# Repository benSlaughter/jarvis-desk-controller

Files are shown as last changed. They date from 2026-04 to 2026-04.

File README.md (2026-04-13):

# Jarvis Desk Controller

Control a Jarvis/Jiecang standing desk via the **RJ-12 port** using the reverse-engineered serial protocol from [phord/Jarvis](https://github.com/phord/Jarvis).

Two platforms are supported:

| Platform | Interface | Features |
|---|---|---|
| **Arduino Uno** | USB Serial CLI | Direct serial commands, interactive terminal |
| **ESP32-C6** | WiFi + MQTT | Home Assistant auto-discovery, OTA updates |

## Hardware Required

### Arduino Uno
- Arduino Uno
- RJ-12 breakout / socket
- 2× 1kΩ resistors (signal protection)
- Hookup wire

### ESP32-C6
- DFRobot Beetle ESP32-C6 (or any ESP32-C6 board)
- RJ-12 breakout / socket
- 1× 1kΩ + 1× 2kΩ resistor (voltage divider for RX line)
- Hookup wire

## Wiring

The RJ-12 port is the 6-pin telephone-style jack on the desk controller (used for the optional Bluetooth add-on). Only the center 4 pins are needed.

```
 RJ-12 Jack (front view, tab down)
 ┌──────────┐
 │ 1 2 3 4 5 6 │
 └──┬─┬─┬─┬─┬─┬──┘
    │ │ │ │ │ │
    NC│ │ │ │ NC
      │ │ │ │
      │ │ │ └── Pin 5: HTX (to desk) ──[1kΩ]── Arduino Pin 3
      │ │ └──── Pin 4: VCC (5V out)    (see power notes below)
      │ └────── Pin 3: DTX (from desk) ──[1kΩ]── Arduino Pin 2
      └──────── Pin 2: GND ──────────── Arduino GND
```

### Connections Summary

| RJ-12 Pin | Label | Arduino Uno | Notes |
|---|---|---|---|
| 1 | NC | — | Not connected |
| 2 | GND | GND | Common ground (REQUIRED) |
| 3 | DTX | Pin 2 (RX) | Via 1kΩ series resistor |
| 4 | VCC | — | 5V from desk (see below) |
| 5 | HTX | Pin 3 (TX) | Via 1kΩ series resistor |
| 6 | NC | — | Not connected |

### Why series resistors?

The 1kΩ resistors protect both the Arduino and the desk controller from shorts, voltage spikes during hot-plugging, and current surges. They don't affect signal integrity at 9600 baud.

### Power Options

**For development (recommended):** Power the Arduino via USB. Leave RJ-12 Pin 4 (VCC) disconnected.

**For standalone deployment:** You *can* power the Arduino from the desk's 5V supply on RJ-12 Pin 4 → Arduino 5V pin. However:

> ⚠️ **Never connect both USB and desk 5V simultaneously** — this back-powers the USB host and can damage your computer or the desk controller. Use a diode or power switch if you need both.

### ESP32-C6 Wiring (Desk-Powered)

The ESP32 can be powered directly from the desk's 5V supply — no USB needed
after the first firmware upload (use OTA for updates).

```
                    DFRobot Beetle ESP32-C6
                    ┌─────────────────────┐
                    │                     │
RJ-12              │  VIN ←── 5V power   │
┌──────┐           │  GND ←── Ground     │
│1    6│           │                     │
│ NC  NC│           │  GPIO17 (RX) ←─┐   │
│      │           │                 │   │
│2 GND─┼──────────→│  GND            │   │
│      │           │                 │   │
│3 DTX─┼──[1kΩ]──┬─┼─────────────────┘   │
│      │         │ │                     │
│      │       [2kΩ]                     │
│      │         │ │                     │
│      │        GND│                     │
│      │           │                     │
│4 VCC─┼──────────→│  VIN (5V)           │
│      │           │                     │
│5 HTX─┼──────────→│  GPIO18 (TX)        │
│      │           │                     │
│6  NC │           └─────────────────────┘
└──────┘
```

| RJ-12 Pin | Label | ESP32-C6 | Notes |
|---|---|---|---|
| 2 | GND | GND | Common ground (REQUIRED) |
| 3 | DTX | GPIO17 (RX) | Via 1kΩ + 2kΩ voltage divider |
| 4 | VCC | VIN (5V) | Powers the ESP32 from desk |
| 5 | HTX | GPIO18 (TX) | Direct connection — 3.3V is fine |

**Parts needed:** 1× 1kΩ resistor, 1× 2kΩ resistor (or 2× 1kΩ in series)

#### Why the Voltage Divider?

The desk sends data at **5V**. The ESP32-C6 GPIOs are rated for **3.3V max**.
Without a divider, 5V goes straight into a 3.3V pin — this will damage the chip.

Two resistors drop the voltage: `5V × 2kΩ / (1kΩ + 2kΩ) = 3.33V` ✅

The TX line (ESP32→desk) doesn't need this because the ESP32 outputs 3.3V,
which the desk's 5V logic reads as HIGH (above the ~2.5V threshold).

> ⚠️ **Never connect USB and desk 5V at the same time** — this back-powers
> the USB host. Disconnect the RJ-12 before plugging in USB, or use OTA
> for all updates after the first upload.
>
> **Current budget:** The desk provides ~300mA at 5V. The ESP32-C6 draws
> ~120-180mA during WiFi activity — well within budget.

## Serial Signal Notes

Live testing on a Jiecang JCB36N2CA (Fully Jarvis) confirmed **normal UART polarity** — standard 9600/8N1 with no inversion needed. Earlier documentation suggested inverted logic, but this was not the case on the tested controller.

The code uses `SoftwareSerial` with `inverse_logic = false` (standard polarity). If you get garbage data, try toggling this flag — some controller models may differ.

## Building & Uploading (PlatformIO)

This project uses [PlatformIO](https://platformio.org/) for build/upload/serial monitoring.

### Setup

1. Install the **PlatformIO IDE** extension in VSCode (`platformio.platformio-ide`)
2. Open this folder in VSCode — PlatformIO detects `platformio.ini` automatically

### Build, Upload & Monitor

Use the PlatformIO toolbar at the bottom of VSCode, or:

```bash
# Arduino Uno
pio run -e uno
pio run -e uno --target upload

# ESP32-C6
pio run -e esp32c6
pio run -e esp32c6 --target upload

# Tests
pio test -e native

# Open serial monitor (115200 baud)
pio device monitor

# Build + upload + monitor in one shot
pio run -e uno --target upload && pio device monitor
```

### ESP32-C6 Setup

1. Copy `include/config.example.h` to `include/config.h`
2. Edit `config.h` with your WiFi SSID/password and MQTT broker IP
3. Build: `pio run -e esp32c6`
4. Upload: `pio run -e esp32c6 --target upload`
5. Monitor: `pio device monitor`

### Home Assistant Integration

The ESP32 firmware publishes MQTT auto-discovery messages. After connecting:

- A **"Jarvis Desk"** device appears automatically in Home Assistant
- **Entities:** height sensor (cm), target height (number), presets 1–4 (buttons), up/down/stop (buttons)
- **Requires** an MQTT broker (e.g., Mosquitto) configured in Home Assistant

### MQTT Topics

| Topic | Direction | Description |
|---|---|---|
| `jarvis-desk/status` | ESP→broker | Online/offline status (retained LWT) |
| `jarvis-desk/height/state` | ESP→broker | Current height in mm (retained) |
| `jarvis-desk/height/set` | broker→ESP | Move to target height in mm |
| `jarvis-desk/preset/set` | broker→ESP | Move to preset (payload: `1`–`4`) |
| `jarvis-desk/command` | broker→ESP | Send command: `up`, `down`, `stop` |
| `jarvis-desk/collision/set` | broker→ESP | Set collision sensitivity: `high`, `medium`, `low` |

### OTA Updates

After the first upload via USB, subsequent updates can use OTA:

```bash
pio run -e esp32c6 --target upload --upload-port jarvis-desk.local
```

### Alternative: Arduino IDE

If you prefer the Arduino IDE, copy files from `src/` and `include/` into a single
folder named `jarvis-desk-controller/`, rename `main.cpp` → `jarvis-desk-controller.ino`,
and open it in the Arduino IDE.

## Usage

Open the Serial Monitor at **115200 baud**. Type commands and press Enter:

| Command | Action |
|---|---|
| `up` / `raise`| Raise desk one step |
| `down`/`lower`| Lower desk one step |
| `1` `2` `3` `4`| Move to memory preset |
| `save1`..`save4`| Save current height to preset|
| `height` | Request current height |
| `settings` | Request all desk settings |
| `limits` | Request min/max limits |
| `wake` | Send wake signal |
| `cm` / `in` | Set display units |
| `status` | Show connection state |
| `help` | List all commands |

### What you'll see

```
=== Jarvis Desk Controller ===
Type 'help' for commands

Waking desk...
[DESK] HEIGHT (05 06 07)  height=1286
> Moving to preset 1
[DESK] HEIGHT (03 CA 07)  height=970
```

## Protocol Reference

- **UART:** 9600 baud, 8N1, normal polarity (not inverted)
- **Packets:** `[addr][addr][cmd][len][params...][checksum][0x7E]`
- **Handset address:** `0xF1 0xF1`
- **Controller address:** `0xF2 0xF2`
- **Checksum:** Low byte of `(cmd + len + params...)`, i.e. `& 0xFF`

Full protocol documentation: https://github.com/phord/Jarvis

## Protocol Discoveries (Live Testing)

Tested on a **Jiecang JCB36N2CA** (Fully Jarvis, RJ-12 port). The RJ-12 interface works standalone — no handset required.

### Confirmed Commands (Handset → Desk)

| Cmd  | Name | Params | Response | Notes |
|---|---|---|---|---|
| 0x01 | RAISE | 0 | HEIGHT stream | Continuous raise when sent repeatedly |
| 0x02 | LOWER | 0 | HEIGHT stream | Continuous lower when sent repeatedly |
| 0x05 | MOVE_1 | 0 | HEIGHT stream | Moves to preset 1, auto-stops |
| 0x06 | MOVE_2 | 0 | HEIGHT stream | Moves to preset 2, auto-stops |
| 0x07 | SETTINGS | 0 | POS_1–4 + HEIGHT | Returns all 4 presets and current height |
| 0x0C | PHYS_LIMITS| 0 | 0x07 (HI HI LO LO) | Physical motion limits: max/min in mm |
| 0x1B | GOTO_HEIGHT| 2 (HI, LO)| 0x1B echo + HEIGHT stream | **Native goto-height.** Desk handles accel/decel/stop |
| 0x20 | LIMITS | 0 | 0x20 (00) | User-set limits bitmask. 0x00 = none set |
| 0x27 | MOVE_3 | 0 | HEIGHT stream | Moves to preset 3, auto-stops |
| 0x28 | MOVE_4 | 0 | HEIGHT stream | Moves to preset 4, auto-stops |
| 0x29 | WAKE | 0 | none (display only) | Wakes display. No data response on RJ-12 |
| 0x2B | STOP | 0 | none | Stops all movement immediately |

### Controller Responses

| Resp | Name | Params | Meaning |
|---|---|---|---|
| 0x01 | HEIGHT | 3 | {P0,P1} = height mm, P2 = flags (always 0x0F here) |
| 0x07 | PHYS_LIMITS| 4 | {P0,P1} = max mm, {P2,P3} = min mm |
| 0x1B | GOTO_ACK | 2 | Echoes target height |
| 0x20 | LIMITS | 1 | Bitmask of user-set limits |
| 0x25–0x28 | POS_1–4 | 2 | Raw encoder value (NOT display mm) |

### Key Observations

- **Normal UART polarity** — standard 9600/8N1, no inversion needed.
- **GOTO_HEIGHT (0x1B)** is the cleanest move method — desk handles acceleration, deceleration, and auto-stop.
- **STOP (0x2B)** halts movement immediately. ESPHome uses wake + stop as an init sequence.
- **Preset values** are raw encoder positions, not display millimeters.
- **Height offset:** Display height has a ~2.4 cm offset from physical (tape-measure) height.
- **Physical limits** on tested unit: 76.5–125.3 cm reported, ~74.1–122.9 cm actual.
- **No-response commands:** 0x0E (UNITS), 0x19 (MEM_MODE), 0x1D (COLL_SENS) — these are setters that likely need parameters, or are RJ-45 only.

## RJ-12 vs RJ-45

This project uses the **RJ-12** interface (6-pin, Bluetooth add-on port). The larger **RJ-45** port (8-pin, handset port) has additional button mux lines (HS0-HS3) not available on RJ-12.

On RJ-12, some responses differ:
- `SETTINGS` returns fewer response packets
- `LIMIT_STOP` and `REP_PRESET` are not sent

## Troubleshooting

| Problem | Try |
|---|-----|
| No response from desk | Check GND connection. Try `wake` command repeatedly. |
| Garbage data | Toggle `inverse_logic` in the SoftwareSerial constructor. Normal polarity (false) confirmed on JCB36N2CA. |
| Partial/corrupt packets | Check series resistors are connected. Reduce Serial.print debug output. |
| Desk doesn't move | The raise/lower commands send a single step. You may need to send repeatedly. |

## License

This project is for personal/educational use. The protocol was reverse-engineered by [phord](https://github.com/phord/Jarvis).

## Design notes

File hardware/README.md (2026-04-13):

# Jarvis Desk Controller — Hardware

Custom PCB to connect a DFRobot Beetle ESP32-C6 to a Jarvis standing desk via
the RJ-12 control port. The board provides a voltage divider on the desk→MCU
data line (5 V → 3.3 V logic) and breaks out power + UART signals.

## Bill of Materials

| Ref | Part | Value | Package / Footprint | Qty | Example Part Number |
|-----|---|---|---|-----|---|
| U1 | DFRobot Beetle ESP32-C6 | — | 2×7 pin header, 2.54 mm pitch | 1 | DFRobot DFR1117 |
| J1 | RJ-12 socket | 6P6C | Through-hole, right-angle | 1 | Amphenol 54601-906LF |
| R1 | Resistor | 1 kΩ | 0805 (or 1/4 W through-hole) | 1 | — |
| R2 | Resistor | 2 kΩ | 0805 (or 1/4 W through-hole) | 1 | — |
| — | Pin headers (female) | 2.54 mm | 1×7, through-hole | 2 | — |

> **Note:** If you use through-hole resistors, increase the board width by a
> few mm to accommodate them.

## Assembly Instructions

### 1. Order the PCB

See [PCB Ordering Guide](#pcb-ordering-guide) below or the detailed
[KiCad Guide](kicad-guide.md) for Gerber generation.

### 2. Solder Components (order matters)

1. **SMD resistors first** (if using 0805) — R1 (1 kΩ) and R2 (2 kΩ). They
   sit on the top side between the RJ-12 footprint and the pin headers.
2. **RJ-12 socket (J1)** — Push through from the top, solder on the bottom.
   The socket opening should face the board edge.
3. **Female pin headers** — Two 1×7 strips for the Beetle. Solder from the
   bottom so the Beetle plugs in on top.
4. **Plug in the Beetle** — The USB-C port should face away from the RJ-12
   socket.

### 3. Connect to Desk

Use a straight-through RJ-12 6P6C cable (all 6 pins wired 1-to-1). Plug one
end into the controller's handset port and the other into J1.

### 4. Flash Firmware

Connect USB-C to the Beetle and flash with PlatformIO:

```bash
pio run -t upload
```

## PCB Ordering Guide

### JLCPCB

1. In KiCad, go to **File → Fabrication Outputs → Gerbers (.gbr)**.
2. Also generate the drill file (Excellon format).
3. Zip all Gerber + drill files together.
4. Go to <https://www.jlcpcb.com/> → **Order Now** → upload the zip.
5. Recommended settings:
   - **Layers:** 2
   - **PCB Thickness:** 1.6 mm
   - **Surface Finish:** HASL (lead-free)
   - **PCB Color:** any (green is cheapest)
   - **Dimensions:** ~35 mm × 25 mm
   - **Qty:** 5 (minimum)
6. Total cost is typically **$2–5 USD** + shipping for 5 boards.

### PCBWay

Same Gerber zip works. Upload at <https://www.pcbway.com/> → **Instant Quote**.
Use the same settings as above.

## Schematic Overview

See [schematic.md](schematic.md) for the full ASCII schematic and component
details.

```
RJ12 Pin 2 (GND) ───────────────── Beetle GND
RJ12 Pin 3 (DTX) ──[R1 1kΩ]──┬── Beetle GPIO17 (RX)
                               │
                            [R2 2kΩ]
                               │
                              GND
RJ12 Pin 4 (VCC) ───────────────── Beetle VIN (5V)
RJ12 Pin 5 (HTX) ───────────────── Beetle GPIO18 (TX)
```

## Files

| File | Description |
|---|---|
| [README.md](README.md) | This file — BOM, assembly, ordering |
| [schematic.md](schematic.md) | ASCII schematic and component details |
| [kicad-guide.md](kicad-guide.md) | Step-by-step KiCad PCB design guide |

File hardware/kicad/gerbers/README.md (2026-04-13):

# Gerber Export Instructions

`kicad-cli` is not installed on this system. To generate Gerber files:

## Option 1: KiCad GUI
1. Open `jarvis-desk.kicad_pcb` in KiCad 8
2. File → Plot (or Fabrication → Plot)
3. Select layers: F.Cu, B.Cu, F.SilkS, B.SilkS, F.Mask, B.Mask, Edge.Cuts
4. Output directory: `gerbers/`
5. Click "Plot"
6. Click "Generate Drill Files" for drill data

## Option 2: kicad-cli (if installed)
```bash
kicad-cli pcb export gerbers --output hardware/kicad/gerbers/ hardware/kicad/jarvis-desk.kicad_pcb
kicad-cli pcb export drill --output hardware/kicad/gerbers/ hardware/kicad/jarvis-desk.kicad_pcb
```

## Fabrication
Upload the generated Gerber + drill files as a zip to your PCB manufacturer (JLCPCB, PCBWay, OSH Park, etc.).

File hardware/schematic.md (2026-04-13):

# Jarvis Desk Controller — Schematic

## Circuit Description

The Jarvis desk communicates over a 5 V UART bus exposed on an RJ-12 (6P6C)
connector. The Beetle ESP32-C6 runs on 3.3 V logic, so the desk→MCU receive
line needs a voltage divider (R1 + R2) to step 5 V down to ~3.3 V. The MCU→desk
transmit line can drive directly since 3.3 V is above the 5 V CMOS high
threshold on most desk controllers.

## ASCII Schematic

```
                        Beetle ESP32-C6
                     ┌───────────────────┐
                     │                   │
 RJ-12 6P6C         │  VIN (5V)  GND    │
┌──────────┐         │   ●        ●      │
│          │         │   │        │      │
│  Pin 1   │  NC     │   │        │      │
│          │         │   │        │      │
│  Pin 2   │──GND────┼───┼────────┘      │
│  (GND)   │         │   │               │
│          │         │   │               │
│  Pin 3   │──DTX──┐ │   │    GPIO17 ●   │
│  (DTX)   │       │ │   │    (RX)   │   │
│          │      ┌┴┐│   │          │   │
│          │      │R││   │          │   │
│          │      │1││   │          │   │
│          │      │ ││   │          │   │
│          │      │1││   │          │   │
│          │      │k││   │          │   │
│          │      └┬┘│   │          │   │
│          │       ├──┼───┼──────────┘   │
│          │       │  │   │               │
│          │      ┌┴┐ │   │               │
│          │      │R│ │   │               │
│          │      │2│ │   │               │
│          │      │ │ │   │               │
│          │      │2│ │   │               │
│          │      │k│ │   │               │
│          │      └┬┘ │   │               │
│          │       │  │   │               │
│          │      GND │   │               │
│          │         │   │               │
│  Pin 4   │──VCC────┼───┘               │
│  (VCC)   │         │                   │
│          │         │        GPIO18 ●   │
│  Pin 5   │──HTX────┼───────(TX)────┘   │
│  (HTX)   │         │                   │
│          │         │                   │
│  Pin 6   │  NC     │                   │
│          │         │                   │
└──────────┘         └───────────────────┘
```

## Simplified Netlist

```
RJ12.2  (GND) ───────────────────────── Beetle.GND
RJ12.3  (DTX) ───── R1 (1kΩ) ────┬──── Beetle.GPIO17 (RX)
                                  │
                              R2 (2kΩ)
                                  │
                                 GND
RJ12.4  (VCC) ───────────────────────── Beetle.VIN (5V)
RJ12.5  (HTX) ───────────────────────── Beetle.GPIO18 (TX)
```

## Voltage Divider Calculation

```
V_out = V_in × R2 / (R1 + R2)
V_out = 5.0 V × 2000 / (1000 + 2000)
V_out = 5.0 V × 0.667
V_out ≈ 3.33 V
```

This is within the ESP32-C6 GPIO input range (max 3.6 V).

## Component Details

### U1 — DFRobot Beetle ESP32-C6 (DFR1117)

- **Pinout (left side, top to bottom):** VIN, GND, 3V3, GPIO0, GPIO1, GPIO15, GPIO23
- **Pinout (right side, top to bottom):** GPIO22, GPIO21, GPIO20, GPIO19, GPIO18, GPIO17, GPIO4
- **Used pins:**
  - VIN — 5 V power input from desk
  - GND — common ground
  - GPIO17 — UART RX (desk DTX → MCU, via voltage divider)
  - GPIO18 — UART TX (MCU → desk HTX, direct)
- **Form factor:** 25 mm × 20.5 mm, 2×7 pin header at 2.54 mm pitch

### J1 — RJ-12 6P6C Socket

- **Type:** Through-hole, right-angle, PCB mount
- **Suggested parts:**
  - Amphenol 54601-906LF
  - Molex 95501-2661
  - SparkFun PRT-00132
- **Pin numbering** (looking into the socket opening, latch on top):
  - Pin 1: NC (not connected)
  - Pin 2: GND
  - Pin 3: DTX (desk transmit → MCU receive)
  - Pin 4: VCC (5 V)
  - Pin 5: HTX (MCU transmit → desk receive)
  - Pin 6: NC (not connected)

### R1 — 1 kΩ Resistor

- **Package:** 0805 SMD (preferred) or 1/4 W axial through-hole
- **Tolerance:** 1% or 5% — either is fine
- **Purpose:** Upper leg of voltage divider

### R2 — 2 kΩ Resistor

- **Package:** 0805 SMD (preferred) or 1/4 W axial through-hole
- **Tolerance:** 1% or 5% — either is fine
- **Purpose:** Lower leg of voltage divider (to GND)

## Net Summary

| Net Name | Connected Pins |
|---|---|
| GND | RJ12.2, Beetle.GND, R2 (low side) |
| VCC_5V | RJ12.4, Beetle.VIN |
| DTX_5V | RJ12.3, R1 (high side) |
| DTX_3V3 | R1 (low side), R2 (high side), Beetle.GPIO17 |
| HTX | RJ12.5, Beetle.GPIO18 |

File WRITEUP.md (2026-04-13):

# Hacking My Jarvis Desk with an Arduino

I wanted to control my Fully Jarvis standing desk from a computer. No WiFi modules,
no cloud services, no Bluetooth — just an Arduino Uno, an RJ-12 cable, and some
reverse-engineering.

This is what I found.

## The Setup

- **Desk:** Fully Jarvis with Jiecang controller
- **Controller port:** RJ-12 (6-pin, the Bluetooth add-on port)
- **Microcontroller:** Arduino Uno
- **Total cost:** ~£20 (Arduino + RJ-12 socket)
- **Wires needed:** 3 (GND, TX, RX)

### Wiring

```
RJ-12 Pin 2 (GND) → Arduino GND
RJ-12 Pin 3 (DTX) → Arduino Pin 2
RJ-12 Pin 5 (HTX) → Arduino Pin 3
Pin 4 (5V)        → Leave disconnected (USB power is fine)
```

No resistors. No level shifting. Both sides are 5V. Done.

## What Went Wrong First

Pretty much everything.

**Wiring mistake #1:** I had pins 4 and 5 swapped — feeding the desk's 5V power
supply into a data pin. Oops.

**Polarity mistake:** The original [phord/Jarvis](https://github.com/phord/Jarvis)
docs describe "5V pullups, mark=low" which sounds like inverted serial. It's not.
The RJ-12 port uses **standard UART polarity**. I figured this out by enabling
debug mode and moving the desk manually — the raw bytes were bit-inverted `F2 F2`
packets, which only makes sense if the serial was reading them wrong.

**The fix:** Normal `SoftwareSerial`, no inverse logic. 9600 baud, 8N1. Standard stuff.

## What Works

Once the wiring and polarity were sorted, everything just... worked.

### Reading
- Current height (in mm or tenths-of-inches depending on display units)
- All 4 memory preset positions
- Physical limits of the desk (min/max travel)
- User-set height limits

### Moving
- Raise/lower (continuous, like holding the button)
- Move to any of the 4 presets
- **Go to a specific height** — `goto 800` moves to 80.0cm and the desk handles
  acceleration, deceleration, and stopping. This was the big discovery.
- Stop movement

### The `goto` Command

This is the good stuff. Command `0x1B` with a 2-byte target height — the desk
does everything. No PID loops, no polling, no "am I there yet". Send it and forget it.

```
goto 800
> Native goto 800mm (80.0cm) from 744mm
[DESK] GOTO_HEIGHT (03 20)  target=80.0cm
[DESK] HEIGHT (02 E9 0F)  74.5cm
[DESK] HEIGHT (03 07 0F)  77.5cm
[DESK] HEIGHT (03 1C 0F)  79.6cm
> Target height reached: 800mm
[DESK] HEIGHT (03 1F 0F)  79.9cm
```

Not documented in phord's README. Found it in the
[ESPHome Jiecang component](https://github.com/Rocka84/esphome_components) source code,
confirmed it works on our hardware.

### The `scan` Command

I added a `scan` command that queries every known read command and dumps the results.
Change a setting on the handset, run scan, diff the output. This is how we mapped
most of the protocol.

## The Protocol

Packets look like this:
```
[addr] [addr] [cmd] [len] [params...] [checksum] [0x7E]
```

- Handset address: `0xF1 0xF1`
- Controller address: `0xF2 0xF2`
- Checksum: `(cmd + len + params) & 0xFF`
- EOM: always `0x7E`

### Commands That Work Over RJ-12

| Cmd | What it does | Response |
|-----|---|---|
| 0x01 | Raise (one step) | HEIGHT stream |
| 0x02 | Lower (one step) | HEIGHT stream |
| 0x05/06 | Move to preset 1/2 | HEIGHT stream, auto-stops |
| 0x07 | Get all settings | POS_1-4 + HEIGHT |
| 0x08 | ??? | 0x05 with FF FF (or 00 06 sometimes) |
| 0x09 | ??? | 0x06 with 01 |
| 0x0C | Physical limits | 0x07 with max/min in mm |
| 0x1B | **Go to height** | Echo + HEIGHT stream, auto-stops |
| 0x1C | ??? | 0x1C with 0x35 (firmware version?) |
| 0x20 | Query limits | 0x20 bitmask + SET_MAX/SET_MIN if set |
| 0x23 | Clear limits | 0x20 confirmation |
| 0x27/28 | Move to preset 3/4 | HEIGHT stream, auto-stops |
| 0x29 | Wake | Wakes display, no data response |
| 0x2B | Stop | Stops movement, no data response |

### What Doesn't Work Over RJ-12

- **Set units** (0x0E) — handset only
- **Anti-collision** (0x1D) — not readable, probably RJ-45 only
- **BT app commands** (0xA0-0xAD) — no response, BT module only
- **Lock/brightness** — handset-local, no protocol traffic at all

### The HEIGHT Response

```
F2 F2 01 03 HH HL P2 checksum 7E
```

`{HH, HL}` = height in mm (CM mode) or tenths-of-inches (inch mode).
`P2` = always `0x0F` on our controller. phord saw `0x07`. Nobody knows what it is.
It doesn't change with units, calibration, movement, or any setting we tested.

## Things We Learned the Hard Way

### Don't Set Min = Max Height

We set both min and max limits to the same height (84.5cm). The desk got stuck.
Completely stuck. Couldn't move from the handset or the Arduino. Clearing the limits
via protocol didn't help — had to **unplug the desk from the wall** and wait.

Power cycle fixed it. But yeah, don't do that.

### Calibration Changes Everything (Uniformly)

When you recalibrate the height on the handset, every height value shifts by the
same offset. Physical limits, current height, all of it. But preset raw encoder
values stay the same — they're hardware positions, not display values.

No software offset needed — just calibrate via the handset and the protocol
values automatically match reality.

### Anti-Collision Sensitivity: Writable Over RJ-12

We physically tested this. Set sensitivity to HIGH via `0x1D 0x01`, raised the desk,
and pushed down with hand pressure — stopped easily at ~91cm. Set to LOW via
`0x1D 0x03`, same test — needed full body weight to trigger it, and it still got
to ~87cm before stopping.

**Setter commands work over RJ-12**, even though we can't read the values back.
The controller accepts and applies them immediately.

| Sensitivity | Command | Force to stop |
|---|---|---|
| HIGH | `0x1D 0x01` | Moderate hand pressure |
| LOW | `0x1D 0x03` | Full body weight |

### 0x1F Is the Controller-Level Lock

We found this by trying something nobody documented — sending 0x1F as a
**setter** instead of a getter:

```
raw 1F 01    → desk locked. Completely. Handset couldn't override it.
raw 1F 00    → didn't unlock
power cycle  → unlocked
```

This is different from the handset's Lock/Unlock menu option (which is local
to the handset). Command 0x1F locks the **motor controller itself**. No known
software unlock — power cycle only.

Don't do this unless you're OK with pulling the plug.

### Presets Are Raw Encoder Values

The POS_1-4 responses are internal encoder tick counts, not display millimetres.
There's a calibration formula somewhere (`height = offset + raw * 0.0642` per
phord/Jarvis#21) but the exact scaling varies by controller.

### The Desk Shows the Fully Logo When You Scan

The SETTINGS command (0x07) is what the handset sends on boot. The controller
wakes up and shows the brand logo. We're basically impersonating a handset.

### Handset-Local Settings

These don't go through the controller at all — no protocol traffic:
- Lock/unlock
- Screen brightness
- Button brightness

We confirmed this by running scan before and after toggling each one. Zero changes.

## RJ-12 vs RJ-45 Capability

| Feature | RJ-12 Read | RJ-12 Write | RJ-45 (per phord) |
|---|---|---|---|
| Height | ✅ | — | ✅ |
| Presets | ✅ raw values | ✅ move + save | ✅ |
| Physical limits | ✅ | — | ✅ |
| User limits | ✅ | ✅ set + clear | ✅ |
| Anti-collision | ❌ | ✅ confirmed | ✅ read + write |
| Units | ❌ | ❌ | ✅ |
| Memory mode | ❌ | Likely works | ✅ |
| Controller lock | ❌ | ✅ (0x1F 01) | Unknown |
| Goto height | — | ✅ (0x1B) | ✅ |
| Stop | — | ✅ (0x2B) | ✅ |

## What's Still Unknown

| Response | Our data | Best guess |
|---|---|---|
| 0x05 (from 0x08) | FF FF (once saw 00 06) | Unknown. Resets on power cycle |
| 0x06 (from 0x09) | 01 | Protocol version or controller type |
| 0x1C (from 0x1C) | 0x35 | Firmware version or model ID |
| HEIGHT P2 byte | always 0x0F | Hardware constant. Doesn't change with anything |
| 0x1F unlock | ??? | No software unlock found. Power cycle only |

## Standing on the Shoulders of Giants

None of this would have been possible without:

- [phord/Jarvis](https://github.com/phord/Jarvis) — the original reverse-engineering
  that started it all
- [Rocka84/esphome_components](https://github.com/Rocka84/esphome_components) —
  the Jiecang ESPHome component that confirmed goto-height works
- [auchter/esphome-jcb35n2](https://github.com/auchter/esphome-jcb35n2) —
  the alternative protocol for simpler controllers
- [Home Assistant community](https://community.home-assistant.io/t/desky-standing-desk-esphome-works-with-desky-uplift-jiecang-assmann-others/383790) —
  the Desky thread with years of collective knowledge
- [pimp-my-desk](https://gitlab.com/pimp-my-desk/desk-control/jiecang-reverse-engineering) —
  more Jiecang protocol details
- Everyone in [Jarvis#33](https://github.com/phord/Jarvis/issues/33) who
  decompiled the BT app and shared their findings

## What's Next

- Proper CLI commands for collision sensitivity, memory mode, units
- Sit/stand timer with reminders

## The ESP32 Port

After getting everything working on the Arduino Uno, the next step was obvious: WiFi.

The **DFRobot Beetle ESP32-C6** is tiny enough to hide behind the desk, and has
HardwareSerial so no more SoftwareSerial timing issues. The main catch is voltage
levels — the ESP32-C6 is 3.3V logic, and the desk outputs 5V. A simple 1kΩ + 2kΩ
voltage divider on the RX line solves that. The TX direction works as-is since
3.3V is above the desk's input threshold.

The whole thing runs off the desk's own 5V supply (RJ-12 Pin 4 → ESP32 VIN).
No USB cable needed after the first firmware upload — OTA handles updates over WiFi.

The firmware connects to WiFi and an MQTT broker, then publishes Home Assistant
auto-discovery messages. Within seconds of powering on, a "Jarvis Desk" device
appears in HA with a height sensor, target height number input, preset buttons,
and movement controls. No YAML configuration needed.

Height updates are debounced — published at most every 500ms during movement,
then a final update when the desk settles. MQTT reconnects with exponential backoff.

The desk protocol library (`JarvisDesk`) is shared between both platforms — only
the entry points (`main_uno.cpp` and `main_esp32.cpp`) differ. The Uno version
is a serial CLI; the ESP32 version is a headless MQTT bridge.

The code is in `src/main_esp32.cpp`. Config goes in `include/config.h`
(copy from `config.example.h`).

The code is a PlatformIO project with 47 unit tests. The research journal with
raw packet captures is in `RESEARCH.md`.

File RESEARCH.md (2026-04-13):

# Jarvis Desk Protocol — Research Journal

> Reverse-engineering notes for a **Fully Jarvis** standing desk with a **Jiecang** controller,
> communicating via the **RJ-12** (Bluetooth add-on) port using an **Arduino Uno**.
>
> Protocol reference: [phord/Jarvis](https://github.com/phord/Jarvis)
> ESPHome reference: [Rocka84/esphome_components](https://github.com/Rocka84/esphome_components/tree/master/components/jiecang_desk_controller)

---

## Hardware Setup

| Item | Details |
|---|---|
| Desk | Fully Jarvis standing desk |
| Controller | Jiecang (model TBD — RJ-12 port present) |
| Handset | Touchpanel with 4 memory presets |
| Microcontroller | Arduino Uno (ATmega328P, 5V logic) |
| Connection | RJ-12 6-pin jack (Bluetooth add-on port) |
| UART | 9600 baud, 8N1, **normal polarity** (NOT inverted) |

### Wiring (RJ-12 → Arduino Uno)

```
RJ-12 Pin 2 (GND) → Arduino GND
RJ-12 Pin 3 (DTX) → Arduino Digital Pin 2 (RX)
RJ-12 Pin 4 (VCC) → Disconnected (USB powered for dev)
RJ-12 Pin 5 (HTX) → Arduino Digital Pin 3 (TX)
```

No resistors, no level shifting — both sides are 5V logic.

---

## Journey Log

### 2026-04-11: Project Scaffolding

- Created PlatformIO project targeting Arduino Uno
- Implemented the phord/Jarvis UART protocol: packet builder, checksum, parser state machine
- Serial monitor CLI with commands: up, down, stop, presets, settings, height, etc.
- Added features: continuous raise/lower with 30s safety timeout, move-to-height,
  raw hex debug mode, auto-detect serial polarity
- 47 native unit tests for protocol and parser — all passing

### 2026-04-11: First Connection Attempt (FAILED)

**Problem:** Auto-detect found no desk on either polarity.

**Root cause 1 — Wiring error:** RJ-12 pins 4 (VCC) and 5 (HTX) were swapped.
Pin 4 is 5V power, pin 5 is the data line. We had the desk's 5V power going into
a data pin and the data line tied to constant 5V.

**Fix:** Disconnected pin 4 (VCC) entirely, moved pin 5 (HTX) to Arduino D3.

**Root cause 2 — Still no response after wiring fix.**
Enabled debug mode and moved desk manually with the RJ-45 handset controller.
Saw data:
```
RX: 83 83 F9 F9 E3 E1 B7 03 00
```

These are **bit-inverted** `F2 F2` packets! The code was trying inverted serial
first (based on the phord docs saying "5V pullups, mark=low"), but this controller
uses **normal/standard UART polarity**.

**Fix:** Changed default to normal polarity. Result:
```
[DESK] HEIGHT (03 12 0F)  height=786
```

**Lesson learned:** The phord/Jarvis docs describe an older controller model.
The Jiecang RJ-12 interface uses standard UART, confirmed by the
ESPHome jiecang_desk_controller component.

### 2026-04-12: Live Testing & Protocol Discovery

Connected via serial monitor. Systematically tested all features and probed
unknown commands.

#### Working Features
- **settings** → Returns POS_1–4 (raw encoder values) + current HEIGHT
- **height** → Works via SETTINGS command (0x07)
- **limits** → Returns 0x00 (no user-set limits)
- **raise/lower** → Continuous movement works, stop works
- **preset 1–4** → Desk moves to stored position, auto-stops
- **debug mode** → Raw hex byte output for troubleshooting

#### Major Discovery: GOTO_HEIGHT (0x1B)

The desk supports a **native goto-height command** — not documented in the
phord/Jarvis README but used by the ESPHome component:

```
Handset sends:  F1 F1 1B 02 HI LO checksum 7E
Desk responds:  F2 F2 1B 02 HI LO checksum 7E  (echo)
                F2 F2 01 03 HH HL 0F checksum 7E  (HEIGHT stream until settled)
```

Where `{HI, LO}` = target height in the same units as HEIGHT reports (mm on this desk).

**Test:** Sent `raw 1B 03 06` (target = 774 = 77.4cm). Desk moved from 80.1cm
down to 77.4cm and auto-stopped. The desk handles acceleration, deceleration,
and final positioning — no need for the crude continuous raise/lower approach!

#### STOP Command (0x2B)

Also discovered (via ESPHome reference) that **0x2B** is a proper STOP command.
The phord docs only document 0x29 (WAKE), which on our controller only wakes
the display and doesn't stop movement or trigger data responses.

---

## Protocol Probe Results

### Commands Tested (Handset → Desk, 0xF1 address)

| Cmd | Name | Params | Response | Our Data | Notes |
|-----|---|---|---|---|---|
| 0x01 | RAISE | 0 | HEIGHT stream | ✅ | Send repeatedly for continuous raise |
| 0x02 | LOWER | 0 | HEIGHT stream | ✅ | Send repeatedly for continuous lower |
| 0x05 | MOVE_1 | 0 | HEIGHT stream | ✅ | Desk moves to preset 1, auto-stops |
| 0x06 | MOVE_2 | 0 | HEIGHT stream | ✅ | Desk moves to preset 2, auto-stops |
| 0x07 | SETTINGS | 0 | POS_1-4 + HEIGHT | ✅ | Returns all 4 presets + current height |
| 0x08 | UNKNOWN_08 | 0 | 0x05 (FF FF) | ✅ | Docs saw 00 00 or FF FF. Unknown purpose |
| 0x09 | UNKNOWN_09 | 0 | 0x06 (01) | ✅ | Consistent with docs. Unknown purpose |
| 0x0C | PHYS_LIMITS | 0 | 0x07 | 04 E5 02 FD | **Confirmed:** {P0,P1}=1253 max, {P2,P3}=765 min (mm) |
| 0x0E | UNITS | 1 | — | no response | Setter — needs param. Sent without param |
| 0x19 | MEM_MODE | 1 | — | no response | Setter — needs param. Sent without param |
| 0x1B | **GOTO_HEIGHT** | 2 (HI,LO) | 0x1B echo + HEIGHT | **03 06** | 🆕 **Native goto!** Desk moves to target, auto-stops |
| 0x1C | UNKNOWN_1C | 0 | 0x1C | 35 | Docs saw 0x0A. We got 0x35 (53). Firmware version? |
| 0x1D | COLL_SENS | 1 | — | no response | Setter — needs param. Sent without param |
| 0x1F | UNKNOWN_1F | 0 | 0x1F | 00 | Matches docs. Unknown purpose |
| 0x20 | LIMITS | 0 | 0x20 | 00 | No user-set min/max limits configured |
| 0x27 | MOVE_3 | 0 | HEIGHT stream | ✅ | Desk moves to preset 3, auto-stops |
| 0x28 | MOVE_4 | 0 | HEIGHT stream | ✅ | Desk moves to preset 4, auto-stops |
| 0x29 | WAKE | 0 | none (display) | ✅ | Wakes desk display. **No data response on RJ-12** |
| 0x2B | **STOP** | 0 | none | ✅ | 🆕 Stops movement. From ESPHome reference |

### Desk Responses Observed (Controller → Handset, 0xF2 address)

| Resp | Name | Params | Meaning |
|---|---|---|---|
| 0x01 | HEIGHT | 3: HH HL 0F | Current height. {P0,P1} = mm. P2 always 0x0F on this controller |
| 0x05 | UNK_05 | 2 | Response to 0x08. Seen: FF FF |
| 0x06 | UNK_06 | 1 | Response to 0x09. Seen: 01 |
| 0x07 | PHYS_LIMITS | 4 | Response to 0x0C. {P0,P1}=max mm, {P2,P3}=min mm |
| 0x1B | GOTO_ACK | 2 | Echoes target height from 0x1B command |
| 0x1C | UNK_1C | 1 | Response to 0x1C. Seen: 0x35 |
| 0x1F | UNK_1F | 1 | Response to 0x1F. Seen: 0x00 |
| 0x20 | LIMITS | 1 | Bitmask: 0x00=none, 0x01=max, 0x10=min, 0x11=both |
| 0x25 | POS_1 | 2 | Preset 1 stored value (raw encoder, NOT display mm) |
| 0x26 | POS_2 | 2 | Preset 2 stored value |
| 0x27 | POS_3 | 2 | Preset 3 stored value |
| 0x28 | POS_4 | 2 | Preset 4 stored value |

---

## Experiment Results

### Experiment 1: HEIGHT P2 vs Units (2026-04-12)

Changed display units via the handset controller and compared HEIGHT responses.

| Mode | HEIGHT P0,P1 | HEIGHT P2 | Conversion |
|---|---|---|---|
| CM | 03 07 (775) | **0x0F** | 77.5cm |
| Inches | 01 31 (305) | **0x0F** | 30.5" = 77.5cm ✅ |

**Conclusions:**
- ✅ Height value changes with units: mm in CM mode, tenths-of-inches in inch mode
- ❌ **P2 does NOT change with units** — still 0x0F in both modes
- ✅ Physical limits (0x07 response) always return mm regardless of units
- ❌ Set-units command (0x0E) does NOT work over RJ-12
- P2 = 0x0F remains a mystery — likely controller model/capability flags

### Experiment 2: BT App Commands (2026-04-12)

Tested decompiled Bluetooth app commands over RJ-12:

| Cmd | Name | Response |
|-----|---|---|
| 0xA0 | PATCH | ❌ No response |
| 0xA2 | FETCH_STAND_TIME | ❌ No response |
| 0xA6 | FETCH_STAND_TIME (alt) | ❌ No response |
| 0xAA | FETCH_ALL_TIME | ❌ No response |
| 0xAD | SET_MEMORY_HEIGHT | ❌ No response |

**Conclusion:** BT app commands are not processed over the RJ-12 UART.
These likely require the BT module to intercept and handle them separately.

### Experiment 3: Limits Set/Clear via RJ-12 (2026-04-12)

**Setting limits works:**
- Set max height at 84.5cm via handset → `LIMITS (01)`, `SET_MAX (03 4D) = 845` ✅
- Set min height at 84.5cm via handset → `LIMITS (10)`, `SET_MIN (03 4D) = 845` ✅
- Matches phord's docs: 0x00=none, 0x01=max-only, 0x10=min-only, 0x11=both

**Clearing limits works (protocol level):**
- `raw 23 01` (clear max) → controller responds `LIMITS (00)` ✅
- `raw 23 02` (clear min) → controller responds `LIMITS (00)` ✅

**⚠️ CRITICAL WARNING — LIMITS INCIDENT:**
After setting min AND max to the same height (84.5cm) and then clearing them
via RJ-12, the desk became **stuck and unable to move**. The controller reported
`LIMITS (00)` (cleared), but the desk refused all movement commands — both from
the Arduino AND from the handset. The handset menu was still accessible but
movement was completely locked out.

**Resolution required:** Power cycling the desk (unplugging from wall power).

**Lesson learned:** Setting min=max to the same height creates a "zero range"
condition that may put the controller into a safety lockout state that persists
even after the limits are cleared via protocol commands. **Never set min and max
to the same height.** The controller may need a full power cycle to recover.

**Also confirmed:**
- Anti-collision sensitivity change: NOT visible in any RJ-12 query (RJ-45 only)
- Lock/unlock: NOT visible in any RJ-12 query (handset-local feature)
- Screen/button brightness: handset-local, no protocol traffic

### Experiment 4: Command Scan (2026-04-12)

Scanned ~40 undocumented command codes across ranges 0x0A–0x4A, 0x80–0x93.
**No new responses found.** The desk controller's RJ-12 command set appears
to be fully mapped. Brightness controls are handset-local.

### Handset Menu Options Mapping

The touchpanel handset has these menu options. Mapping to known protocol commands:

| Menu Option | Likely Command | Status |
|---|---|---|
| Lock/unlock | Handset-only (no protocol change detected) | 🖥️ Local |
| Max height | 0x21 (SET_MAX) | Known |
| Min height | 0x22 (SET_MIN) | Known |
| Units | 0x0E (SET_UNITS) — only works from handset | Known |
| Anti-collision | 0x1D (COLL_SENS) — not readable on RJ-12 | Known |
| Screen brightness | Handset-only (no protocol change detected) | 🖥️ Local |
| Button brightness | Handset-only (no protocol change detected) | 🖥️ Local |
| Memory preset mode | 0x19 (MEM_MODE) | Known |
| Calibrate height | 0x91 (CALIBRATE) — triggers RESET mode | Known |

**Confirmed handset-local settings** (no protocol traffic, no scan changes):
Lock/unlock, screen brightness, button brightness.

### Experiment 5: Height Calibration (2026-04-13)

Calibrated desk height from 76.5cm display → 74.4cm (to match tape measure).

| Value | Before | After | Delta |
|---|---|---|---|
| HEIGHT | 0x0306 (77.4cm) | 0x02E8 (74.4cm) | **-21 (-2.1cm)** |
| PHYS max | 0x04E5 (125.3cm) | 0x04D0 (123.2cm) | **-21** |
| PHYS min | 0x02FD (76.5cm) | 0x02E8 (74.4cm) | **-21** |
| POS_1–4 | unchanged | unchanged | 0 |
| UNK_05 | FF FF | FF FF | 0 |
| UNK_06 | 01 | 01 | 0 |
| UNK_1C | 35 | 35 | 0 |
| UNK_1F | 00 | 00 | 0 |
| HEIGHT P2 | 0x0F | 0x0F | 0 |

**Key findings:**
1. **Calibration shifts all height values uniformly** — same -21 offset applied
   to current height, physical max, and physical min
2. **Preset raw encoder values are NOT affected** — they're truly hardware-level
   encoder positions, independent of the display calibration offset
3. **No software offset needed in firmware** — calibrate via the handset and the
   protocol values automatically reflect real-world heights
4. **RESET mode (0x40)** is sent repeatedly during calibration — the desk goes to
   its lowest position to establish the reference point
5. **HEIGHT P2 byte still unchanged** — not affected by calibration either

**Calibration process observed:**
1. Desk enters RESET mode (display shows "RESET", sends 0x40 responses)
2. Desk moves to absolute lowest position
3. Height reports resume with new calibrated values
4. PHYS_LIMITS update to reflect new offset

### Experiment 6: Anti-Collision Sensitivity via RJ-12 (2026-04-13)

**Write command 0x1D CONFIRMED working over RJ-12!**

Test: goto 1000mm while applying hand pressure to stop the desk.

| Sensitivity | Command | Result |
|---|---|---|
| HIGH (0x01) | `raw 1D 01` | Stopped at ~91.6cm with moderate hand pressure, reversed to 86.8cm |
| LOW (0x03) | `raw 1D 03` | Went all the way to 99.8cm — same pressure didn't trigger stop |

**Confirmed:** Setter commands work over RJ-12, even though we can't read them back.
The controller accepts `0x1D` with params 0x01 (High), 0x02 (Medium), 0x03 (Low)
and the anti-collision behaviour changes immediately.

**This implies all setter commands likely work over RJ-12:**
- 0x0E (UNITS) — needs further testing (didn't work in earlier test)
- 0x19 (MEM_MODE) — untested write
- 0x1D (COLL_SENS) — ✅ CONFIRMED writable

### Experiment 7: 0x1F is LOCK! (2026-04-13)

**🔓 MAJOR DISCOVERY: 0x1F is the controller-level LOCK command!**

Tried out-of-the-box thinking — instead of reading 0x1F, sent it as a setter:
- `raw 1F 01` → desk responded with `01` → **desk completely locked!**
- Handset buttons stopped working
- Handset menu Lock/Unlock also couldn't override it
- `raw 1F 00` did NOT unlock — responded `01` (echoes previous state)
- `raw 1F 02` — no response, didn't unlock either
- Only power cycle unlocked the desk

**Findings:**
- `0x1F` with param `0x01` = **LOCK** the desk controller
- Lock is at the **controller level** — even the handset can't override it
- The query (0x1F with no params) intermittently reports `0x00` (unlocked) or no response
- **No unlock command found** — power cycle required
- Lock state not visible in any scan query

**⚠️ WARNING:** Do not send `0x1F 01` unless you're prepared to power cycle!
The handset's own lock/unlock is a separate, handset-local feature.
This is a deeper controller-level lock with no known software unlock.

**Theory:** The unlock may require a specific sequence (like sending 0x1F 01
twice = toggle), or a different command entirely. Or it may be intentionally
power-cycle-only as a safety feature.

---

## Observations & Open Questions

### HEIGHT Third Byte (P2)
The HEIGHT response always has `0x0F` as the third parameter on our controller.
The phord docs note seeing `0x07` and `0x0F`.

**Experiment result:** P2 does NOT change when switching between CM and inches.
Remaining theories:
- Controller model/capability flags
- Movement state indicator (tested only at rest so far)
- Bit field: 0x0F = 0b00001111 — maybe feature support bitmask?

### Preset Values vs Display Height
Preset positions are stored as raw encoder values, not display millimeters:
```
POS_1 raw=5328   → desk goes to display 77.4cm
POS_2 raw=5616   → desk goes to display ~78.8cm
POS_3 raw=12187  → desk goes to standing height
POS_4 raw=14065  → desk goes to max standing height
```

The relationship between raw encoder values and display mm is non-linear or uses
an offset calibration. The desk controller handles this mapping internally.

### Display Height vs Physical Height
There's a consistent **~2.4cm offset**:
- Desk display shows: 77.4cm
- Tape measure shows: ~75.0cm

This is likely because the desk measures from a mechanical reference point
(e.g., top of the motor column) rather than from the floor. The offset may vary
by desk frame configuration.

### UNKNOWN_1C Response Discrepancy
phord docs saw `0x0A` (10), we got `0x35` (53). This could be:
- Firmware version number
- Feature capability flags
- Controller model identifier
- Anti-collision sensitivity range/setting

### Commands Not Yet Tested
These require parameters and could change desk configuration — test with caution:
- `0x0E` with param 0x00/0x01 — Set units CM/IN
- `0x19` with param 0x00/0x01 — Set memory mode (one-touch/constant-touch)
- `0x1D` with param 0x01/0x02/0x03 — Set anti-collision sensitivity (H/M/L)
- `0x03/0x04/0x25/0x26` — Save presets (PROGMEM) — **will overwrite stored positions!**
- `0x21/0x22` — Set max/min height limits
- `0x23` — Clear min/max limits
- `0x91` — Calibrate — **DANGER: puts desk in RESET mode**

### Commands Not Available on RJ-12
Per the phord docs, these are RJ-45 only:
- `LIMIT_STOP (0x23 response)` — not sent on RJ-12
- `REP_PRESET (0x92 response)` — not sent on RJ-12

---

## Research Findings (2026-04-12)

Compiled from GitHub repos, ESPHome components, Home Assistant community,
Jarvis issues/discussions, and a Jiecang BT app decompile.

### New Commands Found (from BT app decompile — Jarvis issue #33)

| Cmd | Name | Params | Notes |
|-----|---|---|---|
| 0xA0 | PATCH | ? | From Jiecang BT app. Purpose unknown |
| 0xA2 | FETCH_STAND_TIME | ? | Query standing time statistics |
| 0xA6 | FETCH_STAND_TIME (alt) | ? | Alternative stand time query |
| 0xAA | FETCH_ALL_TIME | ? | Query all usage time statistics |
| 0xAD | SET_MEMORY_HEIGHT | ? | Variant-dependent — alternative preset save? |

**Source:** Decompiled Jiecang Bluetooth app `Command.kt`, referenced in
[phord/Jarvis#33](https://github.com/phord/Jarvis/issues/33).

### Bluetooth Protocol Details

The Jiecang BLE module uses the same UART frame format over Bluetooth:
- **BLE Service:** `0xFE60`
- **BLE Characteristics:** `0xFE61` (write) / `0xFE62` (notify)
- **Module:** Lierda LSD4BT-E95ASTD001
- Commands are the same `F1 F1 cmd len params checksum 7E` packets,
  often sent twice for reliability over BLE
- The RJ-12 port is literally the BT module's UART connection —
  we're speaking the same protocol the Bluetooth add-on would

**Source:** [pkg/jiecang/jiecang.go](https://github.com/phord/Jarvis/issues/33)
in a Go implementation referenced in the discussion.

### Preset Calibration Formula

From [phord/Jarvis#21](https://github.com/phord/Jarvis/issues/21):
```
height_mm = offset + raw_encoder_value * 0.0642
```
This explains why our preset values (5328, 5616, 12187, 14065) don't directly
correspond to display mm. The controller applies an offset and a scaling factor
to convert raw encoder ticks to display height.

**Verification with our data:**
```
POS_1 raw=5328, display=77.4cm (774mm)
POS_2 raw=5616, display=~78.8cm (788mm)

Difference: 5616-5328 = 288 raw ticks → 788-774 = 14mm
Scale: 14/288 = 0.0486 mm/tick (close to 0.0642 but not exact)
```
The formula may vary by controller model or our offset may differ.

### HEIGHT Response P2 Byte

Still unresolved across all sources:
- Our controller: always `0x0F`
- phord's controller: saw `0x07` and `0x0F`
- No source has decoded this byte

**Theories:**
- Bit flags for units/mode (0x07 = 0b0111, 0x0F = 0b1111)?
- Controller feature/capability mask?
- Movement state indicator?

**Experiment to try:** Change units to inches (`raw 0E 01`) and check if P2 changes.

### Still Unknown Commands

| Cmd/Resp | Our Data | Other Data | Best Guess |
|---|---|---|---|
| 0x08→0x05 | FF FF | 00 00 or FF FF | Possibly "stored error code" or "last event" — FF FF = none |
| 0x09→0x06 | 01 | 01 | Possibly "controller status" or "protocol version" |
| 0x1C→0x1C | 0x35 (53) | 0x0A (10) | Firmware version or feature capability flags |
| 0x1F→0x1F | 0x00 | 0x00 | Always 0x00 — possibly "child lock" or reserved |

### Alternative Protocol: JCB35N2 (Simple 2-Button Handset)

The JCB35N2 controller (used with basic up/down handsets) uses a completely
different 4-byte protocol:
```
0x01 0x01 0x01 <height_byte>    (during movement)
0x01 0x05 0x01 0xAA             (movement ended)
```
Height byte: each unit ≈ 0.1 inches.
Calibration: `raw_to_inches = (val - min_raw) * 0.1 + min_inches`

**Source:** [auchter/esphome-jcb35n2](https://github.com/auchter/esphome-jcb35n2)

Some controllers support BOTH protocols and may switch between them.

### RJ-12 5th Wire (Pin 1 or 6)

From Jarvis #33: the BT adapter's 5th wire is labeled `BKG` and measured
at 3.3V. Speculation it stands for "background" or "backlight" — possibly
a signal to control the handset display backlight.

---

## Recommendations: Where to Go Next

### Safe Experiments (read-only or reversible)
1. **Decode HEIGHT P2 byte** — Change units to inches (`raw 0E 01`), get
   height report, see if P2 changes. Change back with `raw 0E 00`.
2. **Probe 0x08 after movement** — Send `raw 08` right after the desk moves
   to see if the FF FF changes (error/event log theory).
3. **Try BT app commands** — Send `raw A0`, `raw A2`, `raw AA` to see if
   the controller responds (stand time statistics would be cool!).
4. **Scan for undocumented commands** — Systematically send `raw 0A`,
   `raw 0B`, `raw 0D`, `raw 10`–`raw 18`, `raw 1A`, `raw 1E`, `raw 24`,
   `raw 2A`, `raw 30`–`raw 40` and log any responses.

### Useful Features to Implement
5. **Native goto-height in CLI** — ✅ Done! Test with `goto 802`.
6. **Height offset calibration** — Add a user-configurable offset (-24mm)
   so displayed heights match real tape-measure heights.
7. **Stand time tracking** — If 0xA2/0xAA commands work, display sit/stand
   statistics.
8. **Preset management via protocol** — Save/recall presets using real
   display heights, with the encoder calibration formula.

### Ambitious Goals
9. **WiFi/BLE bridge** — Port to ESP32, expose as BLE device or MQTT client
   for Home Assistant integration.
10. **Sit/stand reminder** — Track time at height and send alerts.
11. **Contribute findings upstream** — Open a discussion on phord/Jarvis
    with our GOTO_HEIGHT, STOP, and physical limits discoveries.

---

## Tools & Resources

- **Protocol docs:** https://github.com/phord/Jarvis
- **ESPHome Jiecang component:** https://github.com/Rocka84/esphome_components/tree/master/components/jiecang_desk_controller
- **ESPHome JCB35N2 component:** https://github.com/auchter/esphome-jcb35n2
- **Loctek/Flexispot controller:** https://github.com/iMicknl/LoctekMotion_IoT
- **Jiecang reverse engineering:** https://gitlab.com/pimp-my-desk/desk-control/jiecang-reverse-engineering
- **Community discussion (HA):** https://community.home-assistant.io/t/desky-standing-desk-esphome-works-with-desky-uplift-jiecang-assmann-others/383790
- **BT app decompile & extras:** https://github.com/phord/Jarvis/issues/33
- **Preset calibration formula:** https://github.com/phord/Jarvis/issues/21
- **JCB35N2 protocol discussion:** https://github.com/phord/Jarvis/discussions/4
- **RJ-12/RJ-45 protocol split:** https://github.com/ssieb/esphome_components/issues/40

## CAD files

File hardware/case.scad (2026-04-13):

// ============================================================================
// Jarvis Desk Controller Case
// Two-part snap-fit enclosure for Beetle ESP32-C6 + custom PCB + RJ-12 socket
// ============================================================================
// Parametric design — adjust variables below to tune fit.
// Print both bottom_case() and top_case() (flip top for printing).
// ============================================================================

/* [PCB & Component Dimensions] */
pcb_length       = 40;    // mm, X-axis (landscape: RJ-12 left, USB right)
pcb_width        = 25;    // mm, Y-axis
pcb_thickness    = 1.6;   // mm, FR4 board

beetle_length    = 25;    // mm (Beetle board height)
beetle_width     = 20.5;  // mm (Beetle board width)
beetle_comp_h    = 5;     // mm, component height above Beetle PCB
beetle_bottom_h  = 2;     // mm, USB connector below Beetle PCB
header_height    = 8;     // mm, pin-header clearance above main PCB

rj12_width       = 15;    // mm, socket body width
rj12_depth       = 13;    // mm, socket body depth
rj12_height      = 12;    // mm, socket body height

usb_width        = 9;     // mm, USB-C opening width (generous)
usb_height       = 3.5;   // mm, USB-C opening height

/* [Case Parameters] */
wall             = 1.5;   // mm, wall thickness
floor_h          = 1.5;   // mm, floor / ceiling thickness
tolerance        = 0.3;   // mm, snap-fit & PCB clearance
snap_depth       = 0.8;   // mm, snap-fit tab protrusion
snap_width       = 6;     // mm, snap-fit tab width
snap_height      = 2;     // mm, snap-fit tab height

post_dia         = 4;     // mm, PCB support post diameter
post_hole_dia    = 2;     // mm, screw pilot or friction-fit pin

vent_slot_w      = 1.5;   // mm, ventilation slot width
vent_slot_l      = 8;     // mm, ventilation slot length
vent_spacing     = 3.5;   // mm, center-to-center vent slot spacing

/* [Derived Dimensions] */
// Internal cavity must fit everything with clearance
cavity_x  = pcb_length + 2 * tolerance;
cavity_y  = pcb_width  + 2 * tolerance;

// Heights: bottom holds PCB + RJ-12; top covers Beetle + headers
// Bottom interior: PCB sits on posts; tallest item below split is RJ-12 socket
pcb_post_h       = 2;     // mm, posts raise PCB off floor for bottom traces
bottom_interior  = pcb_post_h + pcb_thickness + rj12_height + tolerance;
top_interior     = header_height + beetle_comp_h + tolerance;

// Overall outside dimensions
outer_x = cavity_x + 2 * wall;
outer_y = cavity_y + 2 * wall;
bottom_h = floor_h + bottom_interior;
top_h    = floor_h + top_interior;

// Split line is at the top of the bottom shell
split_z  = bottom_h;

// Lip that the top slides over for alignment
lip_h    = 2;
lip_wall = 1;

$fn = 40;

// ============================================================================
// Modules
// ============================================================================

// --- Bottom Case ---
module bottom_case() {
    difference() {
        union() {
            // Outer shell
            difference() {
                rounded_box(outer_x, outer_y, bottom_h, r=2);
                // Hollow interior
                translate([wall, wall, floor_h])
                    cube([cavity_x, cavity_y, bottom_interior + 1]);
            }

            // Inner lip for top alignment
            translate([wall - lip_wall, wall - lip_wall, bottom_h])
                difference() {
                    cube([cavity_x + 2*lip_wall, cavity_y + 2*lip_wall, lip_h]);
                    translate([lip_wall + tolerance/2, lip_wall + tolerance/2, -0.1])
                        cube([cavity_x - tolerance, cavity_y - tolerance, lip_h + 0.2]);
                }

            // PCB support posts (4 corners of PCB area)
            pcb_posts();

            // Snap-fit catches on long sides
            bottom_snaps();
        }

        // RJ-12 opening — on the +X edge (one short/25mm edge of PCB)
        rj12_cutout();

        // USB-C opening — on the -X edge (opposite short edge)
        usb_cutout();

        // Bottom ventilation slots
        bottom_vents();
    }
}

// --- Top Case ---
module top_case() {
    difference() {
        union() {
            // Outer shell (printed upside-down, modeled right-side-up)
            difference() {
                translate([0, 0, split_z])
                    rounded_box(outer_x, outer_y, top_h, r=2);
                // Hollow interior
                translate([wall, wall, split_z - 0.1])
                    cube([cavity_x, cavity_y, top_interior + 0.1]);
            }

            // Inner ribs to press PCB down onto posts (optional hold-down)
            top_pcb_hold_downs();
        }

        // Slot for bottom lip
        translate([wall - lip_wall - tolerance/2, wall - lip_wall - tolerance/2, split_z - 0.1])
            cube([cavity_x + 2*lip_wall + tolerance, cavity_y + 2*lip_wall + tolerance, lip_h + 0.2]);

        // Snap-fit recesses on long sides
        top_snap_recesses();

        // RJ-12 opening (extends into top too)
        rj12_cutout_top();

        // USB-C opening (extends into top)
        usb_cutout_top();

        // Top ventilation slots
        top_vents();
    }
}

// ============================================================================
// Helper Modules
// ============================================================================

module rounded_box(x, y, z, r=2) {
    // Box with rounded vertical edges
    hull() {
        for (dx = [r, x-r], dy = [r, y-r])
            translate([dx, dy, 0])
                cylinder(r=r, h=z);
    }
}

// PCB support posts — near the 4 corners of the PCB footprint
module pcb_posts() {
    inset = 3;  // mm from PCB edge to post center
    positions = [
        [wall + tolerance + inset,                wall + tolerance + inset],
        [wall + tolerance + pcb_length - inset,   wall + tolerance + inset],
        [wall + tolerance + inset,                wall + tolerance + pcb_width - inset],
        [wall + tolerance + pcb_length - inset,   wall + tolerance + pcb_width - inset],
    ];
    for (p = positions) {
        translate([p[0], p[1], floor_h])
            difference() {
                cylinder(d=post_dia, h=pcb_post_h);
                // Pilot hole for alignment pin
                translate([0, 0, -0.1])
                    cylinder(d=post_hole_dia, h=pcb_post_h + 0.2);
            }
    }
}

// Hold-down nubs on the top shell interior — keep PCB from rattling
module top_pcb_hold_downs() {
    inset = 3;
    nub_h = 1.5;
    nub_d = 3;
    // Z position: ceiling minus nub height, pressing onto Beetle top
    z_top = split_z + top_interior - nub_h + floor_h;
    positions = [
        [wall + tolerance + pcb_length/2 - 6, wall + tolerance + inset],
        [wall + tolerance + pcb_length/2 + 6, wall + tolerance + inset],
        [wall + tolerance + pcb_length/2 - 6, wall + tolerance + pcb_width - inset],
        [wall + tolerance + pcb_length/2 + 6, wall + tolerance + pcb_width - inset],
    ];
    for (p = positions)
        translate([p[0], p[1], split_z])
            cylinder(d=nub_d, h=top_interior - 1);
}

// RJ-12 cutout on -X face (left wall)
module rj12_cutout() {
    cy = (outer_y - rj12_width) / 2;
    cz = floor_h + pcb_post_h + pcb_thickness - 1;
    translate([-0.1, cy, cz])
        cube([wall + 0.2, rj12_width, rj12_height + 2]);
}

// RJ-12 cutout extending into top shell
module rj12_cutout_top() {
    cy = (outer_y - rj12_width) / 2;
    cz = split_z - 0.1;
    translate([-0.1, cy, cz])
        cube([wall + 0.2, rj12_width, top_h + 0.2]);
}

// USB-C cutout on +X face (right wall)
module usb_cutout() {
    cx = outer_x - wall - 0.1;
    cy = (outer_y - usb_width) / 2;
    cz = floor_h + pcb_post_h + pcb_thickness + header_height - beetle_bottom_h - usb_height/2;
    translate([cx, cy, cz])
        cube([wall + 0.2, usb_width, usb_height + tolerance]);
}

// USB-C cutout extending into top shell
module usb_cutout_top() {
    cx = outer_x - wall - 0.1;
    cy = (outer_y - usb_width) / 2;
    cz = split_z - 0.1;
    translate([cx, cy, cz])
        cube([wall + 0.2, usb_width, usb_height + tolerance + 2]);
}

// Snap-fit tabs on bottom case (along Y walls)
module bottom_snaps() {
    // Two snaps on each long side (+Y and -Y walls)
    for (side = [0, 1]) {
        for (i = [0, 1]) {
            sx = outer_x * (0.3 + 0.4 * i) - snap_width/2;
            sy = side == 0 ? -snap_depth : outer_y;
            sz = bottom_h - snap_height - 1;
            translate([sx, sy, sz])
                snap_tab();
        }
    }
}

module snap_tab() {
    // Small ramped tab
    hull() {
        cube([snap_width, 0.1, snap_height]);
        translate([0, snap_depth, snap_height * 0.6])
            cube([snap_width, 0.1, snap_height * 0.4]);
    }
}
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

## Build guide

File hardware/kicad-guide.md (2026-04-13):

# Jarvis Desk Controller — KiCad Design Guide

Step-by-step instructions for creating the schematic and PCB layout in
**KiCad 8** (also works with KiCad 7).

---

## 1. Create the KiCad Project

1. Open KiCad → **File → New Project**.
2. Name it `jarvis-desk-controller` and save inside the `hardware/` directory.
3. KiCad creates `.kicad_pro`, `.kicad_sch`, and `.kicad_pcb` files.

---

## 2. Schematic — Add Symbols

Open the schematic editor (`.kicad_sch`).

### 2.1 Add Components

Use **Place → Add Symbol** (shortcut `A`) to add each component:

| Ref | Symbol (KiCad Library) | Notes |
|-----|---|---|
| U1 | `Connector_Generic:Conn_02x07_Odd_Even` | Represents the Beetle pin headers |
| J1 | `Connector:RJ12` or `Connector:6P6C` | If not available, use `Connector_Generic:Conn_01x06` |
| R1 | `Device:R` | 1 kΩ |
| R2 | `Device:R` | 2 kΩ |

> **Tip:** If there's no exact RJ-12 symbol, use a generic 1×6 connector and
> rename the pins to match the RJ-12 pinout.

### 2.2 Beetle ESP32-C6 Pin Mapping

The Beetle has 2×7 pins. Map the `Conn_02x07` symbol pins as follows:

| Symbol Pin | Row | Left Header | Right Header |
|---|-----|---|---|
| 1 / 2 | 1 | VIN | GPIO22 |
| 3 / 4 | 2 | GND | GPIO21 |
| 5 / 6 | 3 | 3V3 | GPIO20 |
| 7 / 8 | 4 | GPIO0 | GPIO19 |
| 9 / 10 | 5 | GPIO1 | GPIO18 |
| 11 / 12 | 6 | GPIO15 | GPIO17 |
| 13 / 14 | 7 | GPIO23 | GPIO4 |

**Pins used in this design:**

| Function | Beetle Pin | Symbol Pin # |
|---|---|---|
| VIN (5V) | Left row, pin 1 | 1 |
| GND | Left row, pin 2 | 3 |
| GPIO18 (TX) | Right row, pin 5 | 10 |
| GPIO17 (RX) | Right row, pin 6 | 12 |

### 2.3 Wire the Schematic

Connect nets as follows:

1. **J1 Pin 4 (VCC)** → **U1 Pin 1 (VIN)**
2. **J1 Pin 2 (GND)** → **U1 Pin 3 (GND)** → **GND power symbol**
3. **J1 Pin 3 (DTX)** → **R1 pad 1**
4. **R1 pad 2** → **R2 pad 1** → **U1 Pin 12 (GPIO17/RX)**
5. **R2 pad 2** → **GND power symbol**
6. **J1 Pin 5 (HTX)** → **U1 Pin 10 (GPIO18/TX)**

Add **GND** power symbols from `power:GND` to all ground connections.

### 2.4 Add Net Labels

For clarity, add net labels:

- `VCC_5V` on the power rail
- `DTX_5V` between J1.3 and R1
- `DTX_3V3` between R1, R2, and GPIO17
- `HTX` between J1.5 and GPIO18

### 2.5 Annotate & Run ERC

1. **Tools → Annotate Schematic** — auto-assign reference designators.
2. **Inspect → Electrical Rules Checker** — fix any errors.
3. Add component values (1k, 2k) via double-click on each resistor.

---

## 3. Assign Footprints

Open **Tools → Assign Footprints** and set:

| Ref | Footprint |
|-----|---|
| U1 | `Connector_PinHeader_2.54mm:PinHeader_2x07_P2.54mm_Vertical` |
| J1 | `Connector_RJ:RJ12_Amphenol_54601` or `Connector_RJ:RJ25_Molex_95501-2661` |
| R1 | `Resistor_SMD:R_0805_2012Metric_Pad1.20x1.40mm` |
| R2 | `Resistor_SMD:R_0805_2012Metric_Pad1.20x1.40mm` |

> **Alternative footprints for through-hole resistors:**
> `Resistor_THT:R_Axial_DIN0207_L6.3mm_D2.5mm_P10.16mm_Horizontal`

> **If the exact RJ-12 footprint isn't in your KiCad library:**
> Search the KiCad footprint library for `RJ` — there are several 6P6C
> options. You can also find footprints on SnapEDA or Ultra Librarian and
> import them.

---

## 4. PCB Layout

### 4.1 Board Setup

1. Open the PCB editor (`.kicad_pcb`).
2. **File → Board Setup**:
   - **Layers:** 2 (F.Cu + B.Cu)
   - **Board thickness:** 1.6 mm
   - **Design Rules:**
     - Minimum trace width: 0.2 mm
     - Minimum clearance: 0.2 mm
     - Minimum via drill: 0.3 mm
     - Minimum via diameter: 0.6 mm

### 4.2 Import Netlist

- **Tools → Update PCB from Schematic** (or press `F8`).
- All components appear in a cluster — spread them out.

### 4.3 Board Outline

Draw the board edge on the **Edge.Cuts** layer:

- **Suggested dimensions: 35 mm × 25 mm** (fits the Beetle with some margin)
- Use **Place → Line** on Edge.Cuts to draw a rectangle.
- Coordinates (origin at bottom-left corner):
  - (0, 0) → (35, 0) → (35, 25) → (0, 25) → close

> You may be able to shrink to ~32 mm × 22 mm depending on the RJ-12 footprint
> size. Adjust after placing components.

### 4.4 Place Components

Suggested placement (approximate coordinates, origin at board center):

```
┌─────────────────────────────────┐
│  ┌─────┐                        │
│  │ J1  │   [R1]  [R2]           │
│  │RJ-12│                        │
│  └─────┘                        │
│                                 │
│  ●  ●  ●  ●  ●  ●  ●          │
│  │  U1 — Beetle Headers  │     │
│  ●  ●  ●  ●  ●  ●  ●          │
│                        ↑USB-C   │
└─────────────────────────────────┘
```

1. **J1 (RJ-12):** Left edge, centered vertically. Socket opening faces left
   (off the board edge).
2. **U1 (Beetle headers):** Centered, below J1. The USB-C end of the Beetle
   should face the right edge for easy access.
3. **R1, R2:** Between J1 and U1, near the DTX/RX trace route.

### 4.5 Mounting Holes (Optional)

If space permits, add 2 mounting holes:

- Symbol: `Mechanical:MountingHole_Pad` (or `MountingHole`)
- Footprint: `MountingHole:MountingHole_2.2mm_M2_Pad_Via`
- Place in opposite corners (e.g., top-right and bottom-left).

### 4.6 Route Traces

Use **Route → Route Single Track** (`X`) with these widths:

| Net | Width | Layer |
|-----|---|---|
| VCC_5V | 0.5 mm | F.Cu |
| GND | 0.5 mm | F.Cu (or ground pour) |
| DTX_5V | 0.25 mm | F.Cu |
| DTX_3V3 | 0.25 mm | F.Cu |
| HTX | 0.25 mm | F.Cu |

**Routing tips:**

- Route power traces (VCC, GND) first with 0.5 mm width.
- Route signal traces (DTX, HTX) at 0.25 mm.
- Keep the voltage divider (R1 → R2 → GND) tight and close to GPIO17.
- All traces should fit on a single layer (F.Cu) for this simple design.

### 4.7 Ground Pour

Add a copper ground pour on **B.Cu** (back copper):

1. **Place → Zone** on B.Cu layer.
2. Draw the zone covering the entire board outline.
3. Assign the zone to the `GND` net.
4. Press `B` to fill the zone.

This provides a solid ground plane and improves signal integrity.

### 4.8 Silkscreen

Add text on the **F.Silkscreen** layer:

- Board name: `Jarvis Desk Ctrl`
- Version: `v1.0`
- Pin labels near J1: `GND`, `DTX`, `VCC`, `HTX`
- Orientation indicator for the Beetle (arrow or dot at pin 1)

---

## 5. Design Rule Check

1. **Inspect → Design Rules Checker** (DRC).
2. Fix any errors (unconnected nets, clearance violations, etc.).
3. Common issues:
   - Unrouted nets → route them or verify intentionally NC.
   - Clearance errors → adjust trace spacing or pad sizes.

---

## 6. Generate Manufacturing Files

### 6.1 Gerber Files

1. **File → Fabrication Outputs → Gerbers (.gbr)**
2. Select all copper layers + silkscreen + solder mask + Edge.Cuts.
3. Output directory: `hardware/gerbers/`

Required layers:

| Layer | KiCad Name | Gerber Suffix |
|---|---|---|
| Front Copper | F.Cu | .GTL |
| Back Copper | B.Cu | .GBL |
| Front Solder Mask | F.Mask | .GTS |
| Back Solder Mask | B.Mask | .GBS |
| Front Silkscreen | F.Silkscreen | .GTO |
| Back Silkscreen | B.Silkscreen | .GBO |
| Board Outline | Edge.Cuts | .GKO |

### 6.2 Drill Files

1. **File → Fabrication Outputs → Drill Files (.drl)**
2. Format: Excellon
3. Output to the same `hardware/gerbers/` directory.

### 6.3 Package for Ordering

```bash
cd hardware/gerbers
zip ../jarvis-desk-ctrl-gerbers.zip *
```

Upload the zip to JLCPCB, PCBWay, or OSH Park.

---

## 7. Quick Reference

| Parameter | Value |
|---|---|
| Board size | 35 mm × 25 mm (adjust to fit) |
| Layers | 2 |
| Thickness | 1.6 mm |
| Min trace width | 0.2 mm |
| Power trace width | 0.5 mm |
| Signal trace width | 0.25 mm |
| Min clearance | 0.2 mm |
| Min via drill | 0.3 mm |
| Component side | Top (F.Cu) |
| Ground pour | Bottom (B.Cu) |

---

## 8. Tips

- **First time with KiCad?** The official
  [Getting Started guide](https://docs.kicad.org/8.0/en/getting_started_in_kicad/getting_started_in_kicad.html)
  is excellent.
- **Can't find a footprint?** Check [SnapEDA](https://www.snapeda.com/) or
  [Ultra Librarian](https://www.ultralibrarian.com/) for free KiCad footprints.
- **Test before soldering:** Use a multimeter to verify continuity on the bare
  PCB before populating components.
- **Order extras:** PCBs are cheap in quantities of 5–10. Order spares in case
  of mistakes.

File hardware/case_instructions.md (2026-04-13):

# Jarvis Desk Controller — 3D-Printed Case

## Overview

A two-part snap-fit enclosure for the Jarvis desk controller, housing:

- DFRobot Beetle ESP32-C6 v1.1 (mounted on headers)
- Custom carrier PCB (~35 × 25 mm)
- RJ-12 6P6C through-hole socket

The case is designed for FDM printing with no supports required.

```
┌─────────────────────────────────┐
│  ╔═══════════╗   Top Shell      │
│  ║  Beetle   ║  (snaps onto     │
│  ║  ESP32-C6 ║   bottom)        │
│  ╚═══════════╝                  │
│  ┌───────────────────────┐      │
│  │     Carrier PCB       │◄─ RJ-12 opening
│  └───────────────────────┘      │
│        Bottom Shell             │
│  (flat base for tape mount)     │
└─────────────────────────────────┘
        ▲               ▲
    USB-C opening    Vent slots
```

## Approximate Case Dimensions

| Dimension | Value |
|---|---|
| Length | ~38 mm |
| Width | ~28 mm |
| Height | ~32 mm (both halves) |

## Print Settings

| Setting | Value |
|---|---|
| **Material** | PLA (PETG also works well) |
| **Layer height** | 0.2 mm |
| **Infill** | 20% |
| **Walls/perimeters** | 3 (gives ~1.2–1.5 mm wall) |
| **Supports** | **None required** |
| **Bed adhesion** | Brim recommended for top shell |
| **Nozzle** | 0.4 mm |
| **Print temp** | 200–210 °C (PLA) |
| **Bed temp** | 60 °C |

### Orientation

- **Bottom shell**: Print as-is (flat bottom on bed). No supports needed.
- **Top shell**: **Flip upside-down** so the flat ceiling sits on the build plate. No supports needed.

## Assembly Instructions

### 1. Prepare the PCB

1. Solder the Beetle ESP32-C6 onto the carrier PCB via pin headers.
2. Solder the RJ-12 socket onto the carrier PCB edge.
3. Flash firmware via USB-C before placing into the case (easier access).

### 2. Insert PCB into Bottom Shell

1. Orient the PCB so the **RJ-12 socket** faces the large opening on one short wall.
2. The **USB-C port** on the Beetle should face the small slot on the opposite short wall.
3. Press the PCB down onto the 4 support posts. The posts have pilot holes — you can optionally use M2 screws or just friction-fit.

### 3. Attach Top Shell

1. Align the top shell over the bottom, matching the lip.
2. Press down firmly until the snap-fit tabs click into place.
3. Verify both the RJ-12 and USB-C openings are unobstructed.

### 4. Mount to Desk

1. Clean the mounting surface (under/behind desk).
2. Apply double-sided mounting tape (e.g., 3M VHB) to the flat bottom of the case.
3. Press firmly onto the desk surface and hold for 30 seconds.
4. Connect the RJ-12 cable from the Jarvis desk handset port.

## Design Notes

- **Ventilation**: Slots on both long side walls and the top ceiling allow passive airflow for the ESP32's WiFi radio heat.
- **Snap-fit tabs**: 4 tabs (2 per long side) with 0.3 mm tolerance. If too tight, lightly sand the tabs. If too loose, add a small drop of CA glue.
- **Parametric**: All dimensions are variables at the top of `case.scad`. Adjust `tolerance` if your printer runs tight or loose.
- **USB-C access**: The opening allows a standard USB-C cable for reflashing without disassembly.

## What It Looks Like

The finished case is a small rounded rectangle roughly the size of a matchbox (38 × 28 × 32 mm). The bottom half is a shallow tray with four internal posts and a flat underside for tape mounting. The top half is a taller shell with ventilation slots on the sides and ceiling. The two halves click together via small snap-fit tabs on the long edges.

One short end has a rectangular opening (~15 mm wide) for the RJ-12 cable connector. The opposite short end has a smaller slot (~9 mm wide) for the USB-C port. Side walls feature a column of narrow ventilation slits, and the top has a grid of small slots for heat dissipation.

The overall aesthetic is clean and minimal — a simple utility enclosure suitable for hiding behind a standing desk.

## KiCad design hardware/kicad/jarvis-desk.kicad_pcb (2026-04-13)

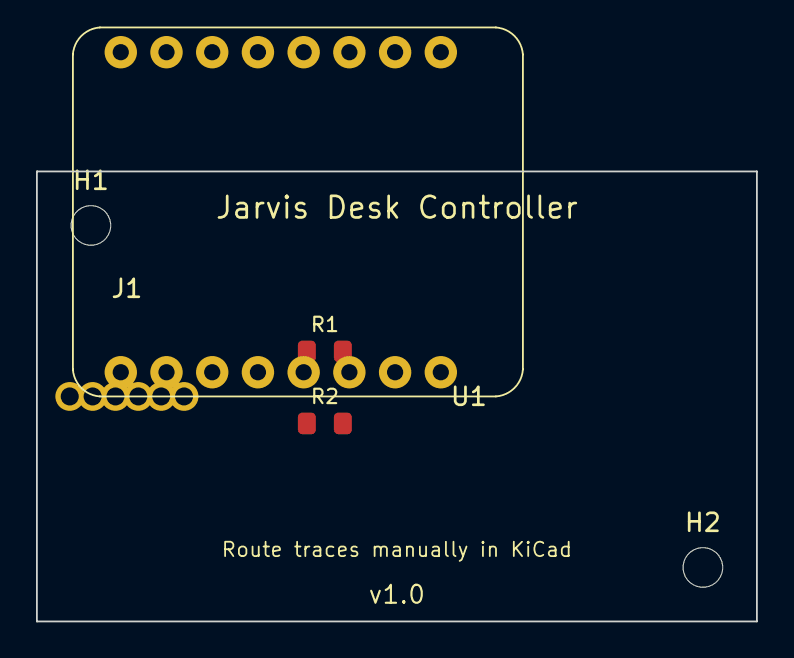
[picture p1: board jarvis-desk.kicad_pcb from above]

Board: 2 copper layers, 40.0 x 25.0 mm, 6 parts (0 on the bottom side), 5 nets, no tracks yet.

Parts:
H1, H2: MountingHole_M2; MountingHole_2.2mm_M2
J1: RJ12_6P6C; RJ12_Amphenol_54601
R1: 1k; R_0805_2012Metric
R2: 2k; R_0805_2012Metric
U1: Beetle_ESP32-C6

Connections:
DTX: J1.3, R1.1
GND: J1.2, R2.2, U1.1, U1.15
HTX: J1.5, U1.12
RX_DIV: R1.2, R2.1, U1.13
VCC_5V: J1.4, U1.14

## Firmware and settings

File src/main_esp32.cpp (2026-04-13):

#ifdef ESP32
#include <Arduino.h>
#include <WiFi.h>
#include <PubSubClient.h>
#include <ArduinoJson.h>
#include <ArduinoOTA.h>
#include "jarvis_desk.h"
#include "config.h"

// ── Hardware ────────────────────────────────────────────────────────
HardwareSerial deskSerial(DESK_UART_NUM);
JarvisDesk desk(&deskSerial);

// ── Network ─────────────────────────────────────────────────────────
WiFiClient wifiClient;
PubSubClient mqtt(wifiClient);

// ── MQTT topics ─────────────────────────────────────────────────────
static const char* TOPIC_STATUS       = "jarvis-desk/status";
static const char* TOPIC_HEIGHT_STATE = "jarvis-desk/height/state";
static const char* TOPIC_HEIGHT_SET   = "jarvis-desk/height/set";
static const char* TOPIC_PRESET_SET   = "jarvis-desk/preset/set";
static const char* TOPIC_PRESET_SAVE  = "jarvis-desk/preset/save";
static const char* TOPIC_COMMAND      = "jarvis-desk/command";
static const char* TOPIC_COLLISION    = "jarvis-desk/collision/set";

// ── Software version ────────────────────────────────────────────────
static const char* SW_VERSION = "1.0.0";

// ── WiFi state ──────────────────────────────────────────────────────
static unsigned long wifiLastAttempt = 0;
static const unsigned long WIFI_RETRY_MS = 5000;

// ── MQTT state ──────────────────────────────────────────────────────
static unsigned long mqttLastAttempt = 0;
static unsigned long mqttBackoff = 1000;
static const unsigned long MQTT_MAX_BACKOFF = 30000;

// ── Height publishing state ─────────────────────────────────────────
static uint16_t lastPublishedHeight = 0;
static unsigned long lastHeightPublishTime = 0;
static bool heightSettled = true;
static const unsigned long HEIGHT_PUBLISH_INTERVAL = 500;

// ── Startup query state ─────────────────────────────────────────────
static bool startupQueriesSent = false;
static unsigned long deskConnectedTime = 0;

// ── Simulator state ─────────────────────────────────────────────────
static bool simMode = false;

// ── Callbacks ───────────────────────────────────────────────────────

void onDeskPacket(const JarvisPacket& pkt) {
    bool fromController = (pkt.address == JARVIS_ADDR_CONTROLLER);
    const char* source = fromController ? "DESK" : "HS";
    const char* name = jarvis_command_name(pkt.command, fromController);

    Serial.printf("[%s] %s", source, name);
    if (pkt.length > 0) {
        Serial.print(" (");
        for (uint8_t i = 0; i < pkt.length; i++) {
            if (i > 0) Serial.print(" ");
            Serial.printf("%02X", pkt.params[i]);
        }
        Serial.print(")");
    }
    if (fromController && pkt.command == RESP_HEIGHT && pkt.length >= 2) {
        uint16_t h = jarvis_decode_height(pkt);
        Serial.printf("  %u.%ucm", h / 10, h % 10);
    }
    if (fromController && pkt.command == RESP_PHYS_LIMITS && pkt.length >= 4) {
        uint16_t pmin = ((uint16_t)pkt.params[0] << 8) | pkt.params[1];
        uint16_t pmax = ((uint16_t)pkt.params[2] << 8) | pkt.params[3];
        Serial.printf("  min=%umm max=%umm", pmin, pmax);
    }
    Serial.println();
}

void onMoveTimeout() {
    Serial.println("! SAFETY TIMEOUT — movement stopped after 30s");
}

void onTargetReached(uint16_t height, bool reached) {
    if (reached) {
        Serial.printf("> Target height reached: %umm\n", height);
    } else {
        Serial.println("! Move-to-height stopped: no height reports (safety timeout)");
    }
}

// ── WiFi ────────────────────────────────────────────────────────────

void handleWifi() {
    if (WiFi.status() == WL_CONNECTED) return;

    unsigned long now = millis();
    if (now - wifiLastAttempt < WIFI_RETRY_MS) return;
    wifiLastAttempt = now;

    Serial.printf("WiFi: connecting to %s...\n", WIFI_SSID);
    WiFi.disconnect();
    WiFi.begin(WIFI_SSID, WIFI_PASS);
}

// ── HA Discovery ────────────────────────────────────────────────────

static void addDeviceBlock(JsonObject dev) {
    JsonArray ids = dev["ids"].to<JsonArray>();
    ids.add("jarvis_desk");
    dev["name"] = "Jarvis Desk";
    dev["mdl"] = "Fully Jarvis (Jiecang)";
    dev["mf"] = "Fully/Jiecang";
    dev["sw"] = SW_VERSION;
}

void publishDiscovery() {
    char buf[512];

    // 1. Height sensor
    {
        JsonDocument doc;
        doc["name"] = "Desk Height";
        doc["uniq_id"] = "jarvis_desk_height";
        doc["stat_t"] = TOPIC_HEIGHT_STATE;
        doc["unit_of_meas"] = "cm";
        doc["ic"] = "mdi:desk";
        doc["val_tpl"] = "{{ (value | float / 10) | round(1) }}";
        addDeviceBlock(doc["dev"].to<JsonObject>());
        serializeJson(doc, buf, sizeof(buf));
        mqtt.publish("homeassistant/sensor/jarvis_desk/height/config", buf, true);
    }

    // 2. Target height number
    {
        JsonDocument doc;
        doc["name"] = "Target Height";
        doc["uniq_id"] = "jarvis_desk_target_height";
        doc["cmd_t"] = TOPIC_HEIGHT_SET;
        doc["stat_t"] = TOPIC_HEIGHT_STATE;
        doc["unit_of_meas"] = "mm";
        doc["step"] = 1;
        doc["min"] = desk.hasPhysicalLimits() ? desk.getPhysicalMin() : 620;
        doc["max"] = desk.hasPhysicalLimits() ? desk.getPhysicalMax() : 1270;
        doc["ic"] = "mdi:arrow-up-down";
        addDeviceBlock(doc["dev"].to<JsonObject>());
        serializeJson(doc, buf, sizeof(buf));
        mqtt.publish("homeassistant/number/jarvis_desk/target_height/config", buf, true);
    }

    // 3. Preset buttons
    for (int i = 1; i <= 4; i++) {
        JsonDocument doc;
        char nameStr[20];
        char uidStr[30];
        char topicStr[60];
        snprintf(nameStr, sizeof(nameStr), "Preset %d", i);
        snprintf(uidStr, sizeof(uidStr), "jarvis_desk_preset_%d", i);
        snprintf(topicStr, sizeof(topicStr), "homeassistant/button/jarvis_desk/preset_%d/config", i);

        doc["name"] = nameStr;
        doc["uniq_id"] = uidStr;
        doc["cmd_t"] = TOPIC_PRESET_SET;
        char payload[2];
        snprintf(payload, sizeof(payload), "%d", i);
        doc["pl_prs"] = payload;
        doc["ic"] = "mdi:numeric";
        addDeviceBlock(doc["dev"].to<JsonObject>());
        serializeJson(doc, buf, sizeof(buf));
        mqtt.publish(topicStr, buf, true);
    }

    // 4. Save Preset buttons
    for (int i = 1; i <= 4; i++) {
        JsonDocument doc;
        char nameStr[24];
        char uidStr[36];
        char topicStr[72];
        snprintf(nameStr, sizeof(nameStr), "Save Preset %d", i);
        snprintf(uidStr, sizeof(uidStr), "jarvis_desk_save_preset_%d", i);
        snprintf(topicStr, sizeof(topicStr), "homeassistant/button/jarvis_desk/save_preset_%d/config", i);

        doc["name"] = nameStr;
        doc["uniq_id"] = uidStr;
        doc["cmd_t"] = TOPIC_PRESET_SAVE;
        char payload[2];
        snprintf(payload, sizeof(payload), "%d", i);
        doc["pl_prs"] = payload;
        doc["ic"] = "mdi:content-save";
        addDeviceBlock(doc["dev"].to<JsonObject>());
        serializeJson(doc, buf, sizeof(buf));
        mqtt.publish(topicStr, buf, true);
    }

    // 5. Up / Down / Stop buttons
    struct { const char* name; const char* id; const char* payload; const char* icon; } buttons[] = {
        {"Raise",  "up",   "up",   "mdi:arrow-up"},
        {"Lower",  "down", "down", "mdi:arrow-down"},
        {"Stop",   "stop", "stop", "mdi:stop"},
    };
    for (auto& b : buttons) {
        JsonDocument doc;
        char uidStr[30];
        char topicStr[60];
        snprintf(uidStr, sizeof(uidStr), "jarvis_desk_%s", b.id);
        snprintf(topicStr, sizeof(topicStr), "homeassistant/button/jarvis_desk/%s/config", b.id);

        doc["name"] = b.name;
        doc["uniq_id"] = uidStr;
        doc["cmd_t"] = TOPIC_COMMAND;
        doc["pl_prs"] = b.payload;
        doc["ic"] = b.icon;
        addDeviceBlock(doc["dev"].to<JsonObject>());
        serializeJson(doc, buf, sizeof(buf));
        mqtt.publish(topicStr, buf, true);
    }

    Serial.println("MQTT: HA discovery published");
}

// ── MQTT callback ───────────────────────────────────────────────────

void mqttCallback(char* topic, byte* payload, unsigned int length) {
    String msg;
    msg.reserve(length);
    for (unsigned int i = 0; i < length; i++) {
        msg += (char)payload[i];
    }

    Serial.printf("MQTT rx [%s]: %s\n", topic, msg.c_str());

    if (strcmp(topic, TOPIC_HEIGHT_SET) == 0) {
        long target = msg.toInt();
        if (target > 0) {
            Serial.printf("> MQTT goto %ldmm\n", target);
            desk.moveToHeight((uint16_t)target);
        }
    } else if (strcmp(topic, TOPIC_PRESET_SET) == 0) {
        int preset = msg.toInt();
        if (preset >= 1 && preset <= 4) {
            Serial.printf("> MQTT preset %d\n", preset);
            desk.moveToPreset((uint8_t)preset);
        }
    } else if (strcmp(topic, TOPIC_PRESET_SAVE) == 0) {
        int preset = msg.toInt();
        if (preset >= 1 && preset <= 4) {
            Serial.printf("> MQTT save preset %d\n", preset);
            desk.savePreset(preset);
        }
    } else if (strcmp(topic, TOPIC_COMMAND) == 0) {
        if (msg == "up") {
            Serial.println("> MQTT raise");
            desk.startRaise();
        } else if (msg == "down") {
            Serial.println("> MQTT lower");
            desk.startLower();
        } else if (msg == "stop") {
            Serial.println("> MQTT stop");
            desk.stop();
        }
    } else if (strcmp(topic, TOPIC_COLLISION) == 0) {
        if (msg == "high") {
            desk.setCollisionSensitivity(COLL_HIGH);
        } else if (msg == "medium") {
            desk.setCollisionSensitivity(COLL_MEDIUM);
        } else if (msg == "low") {
            desk.setCollisionSensitivity(COLL_LOW);
        }
    }
}

// ── MQTT connect ────────────────────────────────────────────────────

void handleMqtt() {
    if (WiFi.status() != WL_CONNECTED) return;
    if (mqtt.connected()) {
        mqtt.loop();
        return;
    }

    unsigned long now = millis();
    if (now - mqttLastAttempt < mqttBackoff) return;
    mqttLastAttempt = now;

    Serial.printf("MQTT: connecting to %s:%d...\n", MQTT_HOST, MQTT_PORT);

    mqtt.setServer(MQTT_HOST, MQTT_PORT);
    mqtt.setBufferSize(512);
    mqtt.setCallback(mqttCallback);

    bool ok;
    if (strlen(MQTT_USER) > 0) {
        ok = mqtt.connect(MQTT_CLIENT_ID, MQTT_USER, MQTT_PASS,
                          TOPIC_STATUS, 1, true, "offline");
    } else {
        ok = mqtt.connect(MQTT_CLIENT_ID, nullptr, nullptr,
                          TOPIC_STATUS, 1, true, "offline");
    }

    if (ok) {
        Serial.println("MQTT: connected");
        mqttBackoff = 1000;

        mqtt.publish(TOPIC_STATUS, "online", true);

        mqtt.subscribe(TOPIC_HEIGHT_SET);
        mqtt.subscribe(TOPIC_PRESET_SET);
        mqtt.subscribe(TOPIC_PRESET_SAVE);
        mqtt.subscribe(TOPIC_COMMAND);
        mqtt.subscribe(TOPIC_COLLISION);

        publishDiscovery();

        // Publish current height if known
        if (desk.getLastHeight() > 0) {
            char buf[8];
            snprintf(buf, sizeof(buf), "%u", desk.getLastHeight());
            mqtt.publish(TOPIC_HEIGHT_STATE, buf, true);
        }
    } else {
        Serial.printf("MQTT: failed rc=%d, retry in %lums\n", mqtt.state(), mqttBackoff);
        mqttBackoff = min(mqttBackoff * 2, MQTT_MAX_BACKOFF);
    }
}

// ── Height publishing (debounced) ───────────────────────────────────

void publishHeight() {
    if (!mqtt.connected()) return;

    uint16_t currentHeight = desk.getLastHeight();
    if (currentHeight == 0) return;
    if (currentHeight == lastPublishedHeight) {
        heightSettled = true;
        return;
    }

    unsigned long now = millis();
    bool moving = desk.isMoving();

    if (moving) {
        // During movement: publish at most every 500ms
        if (now - lastHeightPublishTime < HEIGHT_PUBLISH_INTERVAL) return;
        heightSettled = false;
    } else if (!heightSettled) {
        // Just settled — publish immediately
    } else {
        // Settled and already published — nothing to do
        return;
    }

    char buf[8];
    snprintf(buf, sizeof(buf), "%u", currentHeight);
    bool ok = mqtt.publish(TOPIC_HEIGHT_STATE, buf, true);
    Serial.printf("MQTT publish height %u: %s\n", currentHeight, ok ? "OK" : "FAILED");
    lastPublishedHeight = currentHeight;
    lastHeightPublishTime = now;
    heightSettled = !moving;
}

// ── OTA ─────────────────────────────────────────────────────────────

void setupOta() {
    ArduinoOTA.setHostname(OTA_HOSTNAME);
    if (strlen(OTA_PASSWORD) > 0) {
        ArduinoOTA.setPassword(OTA_PASSWORD);
    }
    ArduinoOTA.onStart([]() { Serial.println("OTA: start"); });
    ArduinoOTA.onEnd([]()   { Serial.println("\nOTA: done"); });
    ArduinoOTA.onProgress([](unsigned int progress, unsigned int total) {
        Serial.printf("OTA: %u%%\r", progress * 100 / total);
    });
    ArduinoOTA.onError([](ota_error_t error) {
        Serial.printf("OTA: error %u\n", error);
    });
    ArduinoOTA.begin();
    Serial.println("OTA: ready");
}

void handleOta() {
    ArduinoOTA.handle();
}

// ── Startup queries ─────────────────────────────────────────────────

void handleStartupQueries() {
    if (startupQueriesSent) return;
    if (desk.getState() != DESK_CONNECTED) return;

    // Wait 500ms after connection before querying
    if (deskConnectedTime == 0) {
        deskConnectedTime = millis();
        return;
    }
    if (millis() - deskConnectedTime < 500) return;

    Serial.println("Desk connected — querying settings and limits");
    desk.requestSettings();
    desk.requestPhysicalLimits();
    startupQueriesSent = true;
}

// ── Arduino entry points ────────────────────────────────────────────

void processSimCommand(const String& cmd) {
    if (cmd.startsWith("height ")) {
        long h = cmd.substring(7).toInt();
        if (h > 0 && h < 2000) {
            Serial.printf("SIM: height = %ldmm\n", h);
            desk.simulateHeightReport((uint16_t)h);
            // Force immediate MQTT publish
            lastPublishedHeight = 0;
            heightSettled = false;
            publishHeight();
        } else {
            Serial.println("SIM: invalid height (use 1-1999)");
        }
    } else if (cmd == "sim on") {
        simMode = true;
        Serial.println("SIM: simulator ON");
    } else if (cmd == "sim off") {
        simMode = false;
        Serial.println("SIM: simulator OFF");
    } else if (cmd == "settings") {
        Serial.println("SIM: injecting settings (limits 620-1270mm)");
        desk.simulateSettingsReport();
    } else if (cmd == "status") {
        Serial.println("──── Status ────");
        Serial.printf("  WiFi:  %s\n", WiFi.status() == WL_CONNECTED ? "connected" : "disconnected");
        if (WiFi.status() == WL_CONNECTED)
            Serial.printf("  IP:    %s\n", WiFi.localIP().toString().c_str());
        Serial.printf("  MQTT:  %s\n", mqtt.connected() ? "connected" : "disconnected");
        Serial.printf("  Desk:  %s\n",
            desk.getState() == DESK_CONNECTED ? "connected" :
            desk.getState() == DESK_WAKING ? "waking" : "disconnected");
        Serial.printf("  Height: %umm\n", desk.getLastHeight());
        Serial.printf("  Sim:   %s\n", simMode ? "ON" : "OFF");
        Serial.println("────────────────");
    } else if (cmd == "help") {
        Serial.println("Commands: height <mm>, sim on/off, settings, status, help");
    } else {
        Serial.printf("Unknown command: %s (try 'help')\n", cmd.c_str());
    }
}

void handleSerialInput() {
    static String inputBuf = "";
    while (Serial.available()) {
        char c = Serial.read();
        if (c == '\n' || c == '\r') {
            if (inputBuf.length() > 0) {
                processSimCommand(inputBuf);
                inputBuf = "";
            }
        } else {
            inputBuf += c;
        }
    }
}

void setup() {
    Serial.begin(115200);
    delay(500);
    Serial.println();
    Serial.println("=== Jarvis Desk Controller — ESP32-C6 ===");
    Serial.println("WiFi + MQTT + Home Assistant");
    Serial.printf("Firmware: %s\n", SW_VERSION);

    // Desk serial
    deskSerial.begin(9600, SERIAL_8N1, DESK_RX_PIN, DESK_TX_PIN);
    desk.onPacket(onDeskPacket);
    desk.onMoveTimeout(onMoveTimeout);
    desk.onTargetReached(onTargetReached);
    desk.begin();

    // WiFi
    WiFi.mode(WIFI_STA);
    WiFi.setHostname(OTA_HOSTNAME);
    WiFi.begin(WIFI_SSID, WIFI_PASS);
    Serial.printf("WiFi: connecting to %s\n", WIFI_SSID);

    // OTA
    setupOta();
}

void loop() {
    desk.update();
    handleSerialInput();
    handleStartupQueries();
    handleWifi();
    handleMqtt();
    handleOta();
    publishHeight();
}
#endif

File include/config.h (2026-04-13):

#ifndef CONFIG_H
#define CONFIG_H

// WiFi
#define WIFI_SSID "TheSprinkleHouse"
#define WIFI_PASS "Tabl3T0p"

// MQTT
#define MQTT_HOST "homeassistant.local"
#define MQTT_PORT 1883
#define MQTT_USER "home-mosquitto"
#define MQTT_PASS "mnb1kuh-ptr8eat-WUB"
#define MQTT_CLIENT_ID "jarvis-desk"

// Desk UART pins (ESP32-C6)
#define DESK_RX_PIN 17   // ESP32 RX ← desk DTX (Beetle pin 13, GPIO17)
#define DESK_TX_PIN 16   // ESP32 TX → desk HTX (Beetle pin 12, GPIO16)
#define DESK_UART_NUM 1

// OTA
#define OTA_HOSTNAME "jarvis-desk"
#define OTA_PASSWORD ""

#endif

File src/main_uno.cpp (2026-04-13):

/**
 * Jarvis Desk Controller — Arduino Uno
 *
 * Communicates with a Jarvis/Jiecang standing desk via the RJ-12 port
 * using the reverse-engineered serial protocol.
 *
 * Wiring (RJ-12 to Arduino Uno):
 *   RJ-12 Pin 2 (GND) → Arduino GND
 *   RJ-12 Pin 3 (DTX) → Arduino Pin 2 (RX) via 1kΩ resistor
 *   RJ-12 Pin 4 (VCC) → Not connected (use USB power for development)
 *   RJ-12 Pin 5 (HTX) → Arduino Pin 3 (TX) via 1kΩ resistor
 *
 * Serial monitor: 115200 baud — type commands to control the desk.
 *
 * Protocol reference: https://github.com/phord/Jarvis
 */

#include <SoftwareSerial.h>
#include "jarvis_desk.h"

// --- Pin definitions ---
#define DESK_RX_PIN 2  // Arduino receives from desk DTX (RJ-12 pin 3)
#define DESK_TX_PIN 3  // Arduino transmits to desk HTX (RJ-12 pin 5)

// Two SoftwareSerial instances — only one active at a time.
// SoftwareSerial's inverse_logic is set at construction and cannot change.
SoftwareSerial deskSerialInverted(DESK_RX_PIN, DESK_TX_PIN, true);   // inverted (5V pullups, mark=low)
SoftwareSerial deskSerialNormal(DESK_RX_PIN, DESK_TX_PIN, false);    // standard polarity

SoftwareSerial* activeDeskSerial = &deskSerialInverted;
bool polarityInverted = true;

JarvisDesk desk(&deskSerialInverted);

// --- Debug hex output ---
static const uint8_t DEBUG_BUF_SIZE = 64;
static uint8_t debugBuf[DEBUG_BUF_SIZE];
static uint8_t debugBufLen = 0;
static unsigned long debugLastByteTime = 0;
static const unsigned long DEBUG_FLUSH_MS = 50;

void onDebugByte(uint8_t b) {
  if (debugBufLen < DEBUG_BUF_SIZE) {
    debugBuf[debugBufLen++] = b;
  }
  debugLastByteTime = millis();
}

void flushDebugLine() {
  if (debugBufLen == 0) return;
  Serial.print(F("RX:"));
  for (uint8_t i = 0; i < debugBufLen; i++) {
    Serial.print(' ');
    if (debugBuf[i] < 0x10) Serial.print('0');
    Serial.print(debugBuf[i], HEX);
  }
  Serial.println();
  debugBufLen = 0;
}

// --- Packet receive callback ---
void onDeskPacket(const JarvisPacket& pkt) {
  bool fromController = (pkt.address == JARVIS_ADDR_CONTROLLER);
  const char* source = fromController ? "DESK" : "HS";
  const char* name = jarvis_command_name(pkt.command, fromController);

  Serial.print(F("["));
  Serial.print(source);
  Serial.print(F("] "));
  Serial.print(name);

  // Print params
  if (pkt.length > 0) {
    Serial.print(F(" ("));
    for (uint8_t i = 0; i < pkt.length; i++) {
      if (i > 0) Serial.print(F(" "));
      if (pkt.params[i] < 0x10) Serial.print(F("0"));
      Serial.print(pkt.params[i], HEX);
    }
    Serial.print(F(")"));
  }

  // Decode height for HEIGHT responses (already in real-world mm)
  // Position presets use raw encoder values — don't convert to cm
  if (fromController && pkt.length >= 2) {
    uint16_t h = ((uint16_t)pkt.params[0] << 8) | pkt.params[1];
    switch (pkt.command) {
      case RESP_HEIGHT:
        Serial.print(F("  "));
        Serial.print(h / 10);
        Serial.print('.');
        Serial.print(h % 10);
        Serial.print(F("cm"));
        break;
      case RESP_GOTO_HEIGHT:
        Serial.print(F("  target="));
        Serial.print(h / 10);
        Serial.print('.');
        Serial.print(h % 10);
        Serial.print(F("cm"));
        break;
      case RESP_POSITION_1:
      case RESP_POSITION_2:
      case RESP_POSITION_3:
      case RESP_POSITION_4:
        Serial.print(F("  raw="));
        Serial.print(h);
        break;
      case RESP_SET_MAX:
      case RESP_SET_MIN:
        Serial.print(F("  = "));
        Serial.print(h);
        break;
    }
  }

  // Decode physical limits (4-byte response)
  if (fromController && pkt.command == RESP_PHYS_LIMITS && pkt.length >= 4) {
    uint16_t pmin = ((uint16_t)pkt.params[0] << 8) | pkt.params[1];
    uint16_t pmax = ((uint16_t)pkt.params[2] << 8) | pkt.params[3];
    Serial.print(F("  min="));
    Serial.print(pmin);
    Serial.print(F("mm max="));
    Serial.print(pmax);
    Serial.print(F("mm"));
  }

  Serial.println();
}

// --- Safety timeout callback ---
void onMoveTimeout() {
  Serial.println(F("! SAFETY TIMEOUT — movement stopped after 30s"));
}

// --- Move-to-height callback ---
void onTargetReached(uint16_t height, bool reached) {
  if (reached) {
    Serial.print(F("> Target height reached: "));
    Serial.print(height);
    Serial.println(F("mm"));
  } else {
    Serial.println(F("! Move-to-height stopped: no height reports (safety timeout)"));
  }
}

// --- Serial monitor command processing ---
String inputBuffer = "";

void processCommand(const String& cmd) {
  String c = cmd;
  c.trim();
  c.toLowerCase();
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

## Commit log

2026-04-11 Initial scaffold: Jarvis desk controller for Arduino Uno via RJ-12
    - jarvis_protocol.h/cpp: UART packet format, checksums, command constants
    - jarvis_desk.h/cpp: State-machine parser, connection management, desk API
    - jarvis-desk-controller.ino: Serial monitor CLI with commands
    - README.md: Wiring guide, usage, and troubleshooting
    Protocol based on https://github.com/phord/Jarvis (RJ-12 interface)
    Uses SoftwareSerial with inverse logic for 5V pull-up signaling.
2026-04-11 Convert to PlatformIO project structure
    - Move sources to src/, headers to include/
    - Rename .ino to main.cpp
    - Add platformio.ini for Arduino Uno (atmelavr)
    - Add .gitignore for PlatformIO build artifacts
    - Update README with PlatformIO build instructions
    Verified: compiles successfully (RAM 54.1%, Flash 28.3%)
2026-04-11 Add continuous movement, move-to-height, debug mode, auto-polarity, and unit tests
    Features:
    - Continuous raise/lower with 30s safety timeout (startRaise/startLower/stop)
    - Move-to-height: 'goto <mm>' moves desk to target with ±5 unit tolerance
    - Raw hex debug mode: 'debug on/off' shows raw bytes for troubleshooting
    - Auto-detect serial polarity on startup (inverted vs normal)
    - 47 native unit tests for protocol, checksum, parser state machine
    CLI commands added: stop, goto, debug on/off, polarity, status updates
    All tests pass. Arduino build: RAM 61.4%, Flash 33.2%.
    [main.cpp, test_protocol.cpp]
2026-04-12 Fix: default to normal UART polarity, add polarity swap command
    Jiecang desks use standard UART (not inverted). Auto-detect now
    tries normal first, defaults to normal on no response.
    Added 'polarity swap' CLI command for manual toggling.
    [main.cpp]
2026-04-12 Decode height in position and limit responses
    POS_1-4, SET_MAX, SET_MIN now show decoded height in cm.
    HEIGHT response also shows formatted cm value (e.g., 77.4cm).
2026-04-12 Fix requestHeight to use SETTINGS cmd, improve output formatting
    - requestHeight() now sends SETTINGS (0x07) instead of WAKE (0x29)
    since WAKE doesn't work on all Jiecang controller models
    - HEIGHT responses show formatted cm (e.g., 77.4cm)
    - Preset positions show raw encoder values (not converted to cm)
    since they use a different encoding with calibration offset
    [main.cpp]
2026-04-12 docs: add protocol discoveries from live testing on JCB36N2CA
    - Add confirmed command table (13 commands tested via RJ-12)
    - Document native GOTO_HEIGHT (0x1B) command
    - Document STOP (0x2B), PHYS_LIMITS (0x0C), controller responses
    - Fix UART polarity: normal polarity confirmed (not inverted)
    - Note height offset (~2.4cm) and raw encoder preset values
    - Note no-response setter commands (UNITS, MEM_MODE, COLL_SENS)
2026-04-12 Add RESEARCH.md — protocol reverse-engineering journal
    Documents the full journey: wiring mistakes, polarity discovery,
    live testing results, and all protocol probe findings including
    the GOTO_HEIGHT (0x1B) and STOP (0x2B) commands.
2026-04-12 feat: implement native GOTO_HEIGHT (0x1B) and STOP (0x2B) commands
    - Add CMD_GOTO_HEIGHT, CMD_STOP, CMD_PHYS_LIMITS protocol constants
    - Add RESP_GOTO_HEIGHT, RESP_PHYS_LIMITS response constants
    - Add gotoHeight() to send native 2-byte goto command
    - Update stop() to send CMD_STOP (0x2B) to desk controller
    - Add requestPhysicalLimits() and physical limits state tracking
    - Simplify moveToHeight() to use native goto (desk auto-stops)
    - Remove overshoot/reverse logic from updateMoveToHeight()
    - Update CLI: goto shows cm, stop sends to desk, add physlimits cmd
    - Update status to show physical limits when known
    - Add command name lookups for new response codes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
    [main.cpp]
2026-04-12 Fix test: UNK_07 renamed to PHYS_LIMITS
    [test_protocol.cpp]
2026-04-12 Update RESEARCH.md with community research findings
    Added: BT app decompile commands (0xA0, 0xA2, 0xAA, 0xAD),
    Bluetooth protocol details (BLE service/chars, Lierda module),
    preset calibration formula, JCB35N2 alternative protocol,
    RJ-12 BKG wire note, and prioritized recommendations.
    Sources: phord/Jarvis#33, #21, Rocka84/esphome_components,
    auchter/esphome-jcb35n2, iMicknl/LoctekMotion_IoT,
    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
2026-04-12 Document experiment results: units test, BT commands, menu mapping
    Experiment 1: HEIGHT P2 byte does NOT change with units (still 0x0F).
    Height values switch between mm and tenths-of-inches correctly.
    Physical limits always return mm. Set-units doesn't work over RJ-12.
    Experiment 2: BT app commands (0xA0-0xAD) get no response over RJ-12.
    These are BT-module-only.
    New: Mapped handset menu options to protocol commands.
    Screen brightness and button brightness are completely undocumented.
    0x1F likely = lock/unlock (got 0x00 = unlocked).
2026-04-12 Document limits experiments, desk stuck incident, and scan results
    WARNING: Setting min=max to same height can lock the desk.
    Power cycle required to recover. Documented in RESEARCH.md.
    Also: lock/brightness are handset-local, anti-collision not
    readable on RJ-12, command scan found no new responses.
2026-04-13 Document calibration experiment: uniform height offset, no software fix needed
    Calibrating from 76.5→74.4cm shifts all height values by -21 uniformly.
    Physical limits, current height all move together. Preset raw encoder
    values are unaffected. P2 byte still unchanged. No firmware offset needed.
2026-04-13 Document anti-collision write confirmed over RJ-12
    HIGH vs LOW physically tested: HIGH stops with moderate hand pressure
    at ~91cm, LOW lets desk reach 100cm with same force. 0x1D setter
    command works over RJ-12 even though the value isn't readable back.
2026-04-13 Update WRITEUP.md with anti-collision, calibration, RJ-12 capability table
    Added: physical anti-collision test results, calibration findings,
    handset-local settings confirmation, RJ-12 vs RJ-45 capability matrix.
2026-04-13 Add CLI commands for desk settings (collision, memmode, units, home)
    Add proper CLI commands for desk settings that were previously only
    accessible via raw hex commands:
    - collision high/medium/low: set anti-collision sensitivity
    - memmode onetouch/constant: set memory preset mode
    - units cm/in: set display units (may not work over RJ-12)
    - home: go to physical minimum height
    Add setCollisionSensitivity() and setMemoryMode() to JarvisDesk class.
    Update help text with all new commands.
    [main.cpp]
2026-04-13 DISCOVERY: 0x1F is controller-level LOCK command!
    raw 1F 01 locks the desk at the controller level. Even the handset
    can't override it. No software unlock found — power cycle required.
    WARNING: Do not use without being prepared to power cycle!
2026-04-13 Add ESP32-C6 PlatformIO environment and config template
    - Add env:esp32c6 using pioarduino platform fork (required for
    ESP32-C6 Arduino support) with PubSubClient and ArduinoJson deps
    - Create include/config.example.h with WiFi, MQTT, UART pin, and OTA
    configuration template
    - Add include/config.h to .gitignore (credentials file)
    - Create src/main_esp32.cpp skeleton that initializes desk UART and
    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
2026-04-13 feat(esp32): full main with WiFi, MQTT, and Home Assistant integration
    - Non-blocking WiFi connection and reconnect
    - MQTT with PubSubClient: LWT, backoff reconnect, 512-byte buffer
    - Home Assistant auto-discovery: height sensor, target number, preset
    buttons (1-4), up/down/stop buttons, collision sensitivity
    - All entities share a device block for proper HA grouping
    - Debounced height publishing (500ms during movement, immediate on settle)
    - ArduinoOTA support with configurable hostname
    - Startup queries for desk settings and physical limits
    - Loop prioritizes desk.update() to never miss serial bytes
    - Packet callback logs all desk traffic to Serial for debugging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
    [main_esp32.cpp]
2026-04-13 docs: add ESP32-C6 wiring, setup, MQTT, HA, and OTA documentation
    - Update README.md with ESP32-C6 wiring (voltage divider), setup guide,
    Home Assistant integration, MQTT topics reference, OTA instructions,
    and multi-platform build commands
    - Update WRITEUP.md with ESP32 port section
    - Update title and hardware section to cover both platforms
2026-04-13 Add desk-powered wiring diagram with voltage divider explanation
    Full ASCII wiring diagram for ESP32-C6 powered from desk 5V.
    Explained why voltage divider is needed (5V→3.3V on RX).
    Added parts list, USB back-power warning, current budget note.
2026-04-13 Add save current height as preset via MQTT
    - Add TOPIC_PRESET_SAVE (jarvis-desk/preset/save) topic
    - Subscribe to new topic in MQTT connect handler
    - Handle save preset command in mqttCallback (presets 1-4)
    - Add 4 Save Preset N HA discovery buttons with mdi:content-save icon
2026-04-13 Add serial simulator mode and fix ESP32-C6 USB-CDC output
    - Add ARDUINO_USB_CDC_ON_BOOT=1 and ARDUINO_USB_MODE=1 build flags
    so Serial maps to HWCDCSerial (USB-CDC JTAG) on ESP32-C6
    - Add simulateHeightReport() and simulateSettingsReport() to JarvisDesk
    for injecting fake desk packets without a physical desk
    - Add serial command handler in main_esp32.cpp loop:
    height <mm>, sim on/off, settings, status, help
    - Enables testing MQTT/HA integration via USB serial console
    [main_esp32.cpp]
2026-04-13 Fix MQTT height publish in simulator mode
    Force immediate publish after simulated height (reset debounce state).
    Add debug logging for MQTT publish success/failure.
    [main_esp32.cpp]
2026-04-13 Add OpenSCAD 3D-printable case for desk controller
    Parametric two-part snap-fit enclosure for Beetle ESP32-C6 + carrier
    PCB + RJ-12 socket. Includes ventilation slots, USB-C access opening,
    PCB support posts, and flat bottom for tape mounting.
    - hardware/case.scad: Full parametric OpenSCAD model
    - hardware/case_instructions.md: Print settings & assembly guide
    [case.scad]
2026-04-13 Add hardware documentation for PCB design
    - hardware/README.md: BOM, assembly instructions, PCB ordering guide
    - hardware/schematic.md: ASCII schematic, component details, net summary
    - hardware/kicad-guide.md: Step-by-step KiCad 8 design walkthrough
    including footprints, board setup, layout, routing, and Gerber export
2026-04-13 Add KiCad 8 project files for Jarvis desk controller PCB
    Create complete KiCad project with schematic, PCB layout, and project file:
    - jarvis-desk.kicad_pro: KiCad 8 project configuration
    - jarvis-desk.kicad_sch: Schematic with RJ12 connector (J1), Beetle ESP32-C6
    as 2x7 pin header (U1), voltage divider resistors R1 (1kΩ) and R2 (2kΩ),
    and power/ground symbols
    - jarvis-desk.kicad_pcb: PCB layout (35x25mm) with component placement,
    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
    [jarvis-desk.kicad_pcb, jarvis-desk.kicad_sch]
2026-04-13 Fix KiCad files: remove invalid semicolon comments
    KiCad S-expression format doesn't support ; comments.
    Removed all comment lines from .kicad_pcb and .kicad_sch.
    Parentheses verified balanced in both files.
    [jarvis-desk.kicad_pcb, jarvis-desk.kicad_sch]
2026-04-13 Clean up KiCad temp files, update gitignore
2026-04-13 Fix PCB layout: move Beetle header within board bounds
    U1 (2x7 header) was at Y=12.5, causing pins 11-14 to extend past
    the 25mm board edge. Moved to Y=4.88 (vertically centered).
    Updated all trace routing to match new pin positions.
    Verified: all components and traces within 35x25mm board outline.
    [jarvis-desk.kicad_pcb]
2026-04-13 Rebuild PCB with official DFRobot Beetle ESP32-C6 footprint
    - Copy official kicad_mod and kicad_sym from DFRobot to hardware/kicad/libs/
    - Rewrite PCB (38x30mm board) using official 16-pin Beetle footprint
    with correct pad positions (2x8, 2.54mm pitch, 17.78mm row spacing)
    - Update schematic to use official Beetle_ESP32-C6 symbol
    - Route all nets: GND, VCC_5V, DTX→R1→R2 voltage divider→GPIO17,
    HTX→GPIO16, with back copper GND pour
    - Change DESK_TX_PIN from 18 to 16 in config.h and config.example.h
    (GPIO18 not on Beetle headers; GPIO16 is pin 12, adjacent to GPIO17)
    - Pin assignments: GPIO17 (pin 13) = RX, GPIO16 (pin 12) = TX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
    [jarvis-desk.kicad_pcb, jarvis-desk.kicad_sch]
2026-04-13 Update OpenSCAD case for new 38x30mm PCB dimensions
    PCB resized from 35x25mm to 38x30mm to fit the official
    Beetle ESP32-C6 footprint (16-pin, 20.5x25mm body).
    Case is parametric — only two values changed.
    [case.scad]
2026-04-13 Fix PCB layout orientation and update case to match
    - Board: 40mm × 25mm landscape (was 38×30)
    - Beetle ESP32-C6 at (28, 12.5) with 90° CW rotation, USB-C facing right edge
    - RJ-12 connector at (5, 12.5) on left edge
    - R1 at (16, 10), R2 at (16, 14) between connectors
    - Mounting holes at (3, 3) and (37, 22)
    - Removed manual trace routing (route in KiCad after verifying pad positions)
    - Updated case.scad: RJ-12 cutout on -X (left), USB-C cutout on +X (right)
    - Removed KiCad backup zip from repo
    [case.scad, jarvis-desk.kicad_pcb]
2026-04-13 Fix Beetle placement: move left 1mm to prevent board overhang
    Beetle at (27,12.5,90) — body now spans X=14.5-39.5 (within 40mm board).
    Full dimensional audit passed: all components within bounds, case cutouts
    aligned, mounting holes match case posts.
    [jarvis-desk.kicad_pcb]
